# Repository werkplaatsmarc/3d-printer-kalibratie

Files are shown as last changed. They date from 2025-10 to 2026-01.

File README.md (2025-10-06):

# 🛠️ Werkplaats Marc - 3D Printer Kalibratie

**Gratis Nederlandse kalibratie bestanden en tutorials voor perfecte 3D prints**






## 🎯 Complete kalibratie serie

Deze repository bevat **5 van de 10 essentiële kalibratie tests** voor je 3D printer. Alle tests (inclusief Bed Nivellering, Z-Afstand, E-Steps, PID Tuning en Flow Rate) zijn te vinden op **<a href="https://werkplaatsmarc.be" target="_blank">werkplaatsmarc.be</a>** met complete Nederlandse tutorials.

## 📦 Wat zit er in deze repository?

Deze repository bevat **kant-en-klare kalibratie bestanden** voor je 3D printer, allemaal met **Nederlandse instructies**. Geen gedoe met zelf towers maken - download, print, kalibreer.

### 🌡️ Temperatuur Towers

- **PLA** (180-220°C) - Vind de perfecte print temperatuur
- **PETG** (220-250°C) - Test layer adhesie en transparantie
- **ABS** (210-250°C) - Optimaal voor gesloten printers
- **TPU** (210-230°C) - Speciaal voor flexibel filament

### 🔄 Retraction Towers

- **Direct Drive** (1-6mm) - Korte filament pad optimalisatie
- **Bowden** (4-9mm) - Lange tube compensatie
- **TPU Flexibel** (7-12mm) - Voorkomt jamming bij flexibel materiaal

### 🌉 Bridging Test

- **Universeel bridging test** - Optimaliseer cooling en speed voor perfecte overspanningen

### 🎯 Linear Advance Test

- **Universeel pattern** - Werkt voor Marlin K-Factor én Klipper Pressure Advance
- Elimineer blobs en krijg CNC-scherpe hoeken

### 🔧 Input Shaping (GEAVANCEERD)

- **Python scripts** voor automatische resonantie analyse met ADXL345 accelerometer
- **Data verzameling en analyse** - Identificeer resonantie frequenties automatisch
- **Marlin & Klipper** firmware configuratie gegenereerd
- Elimineer ghosting en ringing met 50-80% reductie
- 20-40% hogere betrouwbare print snelheden
- **Volledige Nederlandse tutorial** beschikbaar in `input-shaping/README_NL.md`

### 📚 Nederlandse Instructies

Elke test komt met een **complete setup gids** in het Nederlands:

- Hoe te printen
- Hoe te evalueren
- Hoe waarden toe te passen in je firmware
- Troubleshooting tips

## 🔟 Volledige kalibratie roadmap

Voor de **complete 10-stappen kalibratie** (van bed nivellering tot input shaping), bezoek:
👉 **<a href="https://werkplaatsmarc.be" target="_blank">werkplaatsmarc.be</a>**

Daar vind je:

1. Bed Nivellering
2. Z-Afstand
3. E-Steps
4. Temperatuur ⬅️ _in deze repo_
5. PID Tuning
6. Retraction ⬅️ _in deze repo_
7. Linear Advance ⬅️ _in deze repo_
8. Flow Rate
9. Bridging ⬅️ _in deze repo_
10. Input Shaping ⬅️ _in deze repo_

## 🚀 Hoe te gebruiken?

### Optie 1: Download via website (makkelijkst)

Bezoek **<a href="https://werkplaatsmarc.be" target="_blank">werkplaatsmarc.be</a>** en download de bestanden die je nodig hebt. Elke downloadknop geeft je automatisch het STL/3MF bestand + Nederlandse setup gids.

### Optie 2: Clone deze repository

```bash
git clone https://github.com/werkplaatsmarc/3d-printer-kalibratie.git
cd 3d-printer-kalibratie
```

### Optie 3: Input Shaping Setup

Voor geavanceerde Input Shaping kalibratie:

```bash
cd input-shaping
pip install -r requirements.txt
python adxl_collect.py
python analyze_data.py
```

Zie `input-shaping/README_NL.md` voor de complete tutorial.

## 📁 Repository structuur

```
3d-printer-kalibratie/
├── retraction-towers/
│   ├── retractie-toren-direct-drive-afstand-1-6.3mf
│   ├── retractie-toren-bowden-afstand-4-9.3mf
│   └── retractie-toren-tpu-flexibel-afstand-7-12.3mf
│
├── temperatuur-towers/
│   ├── temperatuur-toren-PLA-180-220.stl
│   ├── temperatuur-toren-PETG-220-250.stl
│   ├── temperatuur-toren-ABS-210-250.stl
│   └── temperatuur-toren-TPU-210-230.stl
│
├── bridging-tests/
│   └── bridging-test-universeel.stl
│
├── linear-advance-tests/
│   └── linear-advance-test-pattern.stl
│
├── input-shaping/
│   ├── adxl_collect.py          # Data verzameling script
│   ├── analyze_data.py           # Automatische analyse
│   ├── requirements.txt          # Python dependencies
│   ├── README_NL.md              # Volledige Nederlandse tutorial
│   └── ringing_tower.stl         # Test print voor validatie
│
└── instructies/
    ├── retraction-setup-gids.txt
    ├── temperatuur-tower-setup.txt
    ├── bridging-setup-gids.txt
    └── linear-advance-setup.txt
```

## 🎥 Video tutorials

Alle kalibratie stappen worden uitgelegd in de **Werkplaats Marc YouTube serie**:

- <a href="https://youtube.com/@werkplaatsmarc" target="_blank">Basis Kalibratie Deel 1</a> - Komt binnenkort
- <a href="https://youtube.com/@werkplaatsmarc" target="_blank">Geavanceerde Kalibratie Deel 2</a> - Komt binnenkort
- <a href="https://youtube.com/@werkplaatsmarc" target="_blank">Input Shaping Tutorial</a> - Komt binnenkort

## 🤝 Bijdragen

Verbeteringen zijn welkom! Open een issue of pull request als je:

- Betere test models hebt
- Fouten vindt in de instructies
- Nieuwe kalibratie tests wilt toevoegen

## 📝 Licentie

MIT License - Gebruik vrijelijk, ook commercieel. Attributie gewaardeerd maar niet verplicht.

## 🔗 Links

- **Website:** <a href="https://werkplaatsmarc.be" target="_blank">werkplaatsmarc.be</a>
- **YouTube:** <a href="https://youtube.com/@werkplaatsmarc" target="_blank">@werkplaatsmarc</a>
- **Discord:** <a href="https://discord.gg/UfztVFcR7g" target="_blank">Community chat</a>

## ❓ Veelgestelde vragen

**Q: Werken deze bestanden met mijn slicer?**  
A: Ja! STL bestanden werken met Cura, PrusaSlicer, Simplify3D, en alle andere slicers. 3MF bestanden hebben extra metadata maar werken ook overal.

**Q: Moet ik iets aanpassen in mijn slicer?**  
A: Voor temperatuur towers: ja, volg de meegeleverde instructies om temperatuur te wijzigen per laag. Voor bridging en linear advance: nee, gewoon printen.

**Q: Wat is Input Shaping en heb ik dat nodig?**  
A: Input Shaping is een geavanceerde techniek om ghosting en ringing te elimineren. Het is optioneel maar geeft drastische kwaliteitsverbetering. Vereist een ADXL345 accelerometer sensor en Python kennis.

**Q: Ik heb een probleem met een test, waar kan ik hulp krijgen?**  
A: Join de <a href="https://discord.gg/UfztVFcR7g" target="_blank">Discord community</a> of stel een vraag onder de YouTube video's. De community helpt graag!

**Q: Waar zijn de andere 5 kalibratie tests?**  
A: Bezoek <a href="https://werkplaatsmarc.be" target="_blank">werkplaatsmarc.be</a> voor de complete 10-stappen kalibratie roadmap met alle tutorials en downloads.

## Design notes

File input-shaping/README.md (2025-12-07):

# 🔧 Input Shaping Kalibratie - Werkplaats Marc

**Nederlandse Input Shaping Tutorial voor 3D Printers**

Elimineer ghosting en ringing op je 3D printer met automatische resonantie analyse. Deze repository bevat tools en documentatie voor zowel **Marlin** als **Klipper** firmware.





---

## 🎯 Welke Firmware Heb Je?

Input Shaping werkt anders op Marlin en Klipper. Kies hieronder:

| **Firmware** | **Gebruik Deze Tools** | **Workflow** |
| --- | --- | --- |
| 🔴 **Marlin**  | ✅ Tools in deze repo  | ADXL345 → USB → PC → Automatische analyse → G-code |
| 🟢 **Klipper** | ❌ Geen tools nodig | ADXL345 → Raspberry Pi → Native Klipper commands |

### Hoe weet ik welke firmware ik heb?

**Methode 1: M115 Command**

```gcode
M115
```

Response toont firmware type en versie.

**Methode 2: Interface**

- **Marlin:** LCD scherm, SD kaart, soms OctoPrint
- **Klipper:** Altijd Raspberry Pi + Mainsail/Fluidd web interface

**Methode 3: Raspberry Pi**

- **Heeft Raspberry Pi:** Waarschijnlijk Klipper
- **Geen Raspberry Pi:** Waarschijnlijk Marlin

---

## 📦 Repository Structuur

```
input-shaping/
├── README.md                          ← Je bent hier
├── ringing_tower.stl                  ← Test print model (beide firmware)
│
├── Marlin/                            ← Voor Marlin gebruikers
│   ├── README-MARLIN.md              ← Volledige Marlin guide
│   ├── Windows/
│   │   ├── adxl_verzameling.bat      ← Windows GUI tool
│   │   ├── INSTALL.bat               ← Windows installer
│   │   └── python/adxl_collect.py    ← Data verzamel + analyse script
│   └── Mac-Linux/
│       ├── adxl_verzameling.sh       ← Mac/Linux tool
│       ├── install.sh                ← Mac/Linux installer
│       └── python/adxl_collect.py    ← Data verzamel + analyse script
│
└── Klipper/                           ← Voor Klipper gebruikers
    └── README-KLIPPER.md             ← Link naar native Klipper tools
```

---

## 🚀 Quick Start

### Voor **Marlin** Gebruikers:

1. **Download de juiste tool:**

   - **Windows:** Download `Marlin/Windows/` map
   - **Mac/Linux:** Download `Marlin/Mac-Linux/` map

2. **Installeer (eerste keer):**

   - **Windows:** Dubbelklik `INSTALL.bat`
   - **Mac/Linux:** Run `./install.sh`

3. **Gebruik de tool:**

   - **Windows:** Dubbelklik `adxl_verzameling.bat`
   - **Mac/Linux:** Run `./adxl_verzameling.sh`

4. **Kies optie [1]** - Volledige kalibratie
5. **Wacht ~30 seconden** voor data verzameling

6. **Krijg direct resultaten!** ⚡

   ```
   📈 X-as resonantie: 35.2 Hz
   📈 Y-as resonantie: 29.8 Hz

   ⚙️ MARLIN G-CODE:
   M593 X F35.2 D0.1
   M593 Y F29.8 D0.1
   M500
   ```

7. **Kopieer G-code** naar je printer terminal

8. **Klaar!** Print en geniet van 50-80% minder ringing! 🎉

### Voor **Klipper** Gebruikers:

👉 Lees `Klipper/README-KLIPPER.md` voor native Klipper workflow.

**TL;DR:** Sluit ADXL345 aan op je Raspberry Pi en gebruik Klipper's eigen tools - deze repository tools zijn NIET nodig voor Klipper!

---

## 📊 Wat Doet Input Shaping?

**Voor Input Shaping:**

- 😞 Zichtbare ringing (golfpatronen) rondom hoeken
- 😞 Ghosting bij snelle bewegingen
- 😞 Beperkte print snelheden
- 😞 Kwaliteit vs snelheid trade-off

**Na Input Shaping:**

- 😊 50-80% reductie in ringing
- 😊 Gladde oppervlakken bij hoge snelheid
- 😊 20-40% hogere betrouwbare snelheden
- 😊 Professionele print kwaliteit

---

## 🔧 Benodigde Hardware

### Voor Marlin:

- BigTreeTech ADXL345 v2.0 (of compatibel)
- USB-C kabel
- Computer (Windows, Mac of Linux)
- 3D printer met Marlin 2.1.x+ firmware

### Voor Klipper:

- ADXL345 accelerometer
- Raspberry Pi met Klipper
- Jumper wires (voor GPIO verbinding)

---

## 📚 Volledige Documentatie

- **Marlin gebruikers:** Lees `Marlin/README-MARLIN.md`
- **Klipper gebruikers:** Lees `Klipper/README-KLIPPER.md`
- **Website:** [werkplaatsmarc.be/input-shaping.html](https://werkplaatsmarc.be/input-shaping.html)
- **YouTube:** [@werkplaatsmarc](https://youtube.com/@werkplaatsmarc)

---

## ❓ Veelgestelde Vragen

### Kan ik Input Shaping gebruiken met mijn printer?

**Marlin:**

- ✅ Marlin 2.1.x of nieuwer
- ✅ `INPUT_SHAPING_X` en `INPUT_SHAPING_Y` enabled in firmware
- ✅ Check met `M593` command (geen error = ondersteund)

**Klipper:**

- ✅ Alle Klipper versies ondersteunen Input Shaping
- ✅ Gewoon `[input_shaper]` toevoegen aan printer.cfg

### Hoe vaak moet ik kalibreren?

Herkalibreer wanneer je:

- 🔧 Mechanische wijzigingen maakt (nieuwe riemen, lagers, etc.)
- 🏗️ Printer verplaatst of herboouwt
- 📦 Grote hardware upgrades doet
- 📉 Verslechtering in print kwaliteit ziet

**Niet nodig bij:**

- ✅ Verschillende filament types
- ✅ Verschillende print snelheden
- ✅ Normale gebruik

### Werkt dit met alle slicers?

Ja! Input Shaping werkt op firmware niveau, dus het werkt met:

- ✅ Cura
- ✅ PrusaSlicer
- ✅ SuperSlicer
- ✅ Simplify3D
- ✅ Alle andere slicers

---

## 🆘 Hulp Nodig?

1. **Lees de README** voor jouw firmware (Marlin of Klipper)
2. **Check de troubleshooting** sectie in de README
3. **Bekijk de YouTube tutorials**
4. **Stel vragen** via GitHub Issues
5. **Join de Discord** community

---

## 🌐 Links & Resources

- **Website:** [werkplaatsmarc.be](https://werkplaatsmarc.be)
- **YouTube:** [@werkplaatsmarc](https://youtube.com/@werkplaatsmarc)
- **Discord:** [discord.gg/UfztVFcR7g](https://discord.gg/UfztVFcR7g)
- **GitHub:** [github.com/werkplaatsmarc](https://github.com/werkplaatsmarc)

---

## 📜 Changelog

### v2.0.0 (December 2025)

- 🎉 **GROTE UPDATE:** Geïntegreerde FFT analyse
- ✨ Direct G-code output na verzameling
- ✨ Geen web upload meer nodig
- ✨ Offline workflow
- ✨ Verbeterde gebruikerservaring
- 🐛 Diverse bug fixes

### v1.0.0 (Oktober 2025)

- 🎉 Eerste release
- ✅ Windows en Mac/Linux tools
- ✅ Online web analyzer
- ✅ Nederlandse documentatie

---

## 📄 Licentie

MIT License - Zie LICENSE bestand voor details.

Open source project voor de Nederlandse maker community! 🇳🇱

---

## 💖 Credits

**Ontwikkeld door:** Marc - Werkplaats Marc  
**Community:** Nederlandse 3D printing makers  
**Dank aan:** Alle testers en contributors!

---

**Veel succes met je Input Shaping kalibratie!** 🚀

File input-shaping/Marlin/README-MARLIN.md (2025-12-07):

# 🔴 Input Shaping voor Marlin - Werkplaats Marc

**Volledige Nederlandse Guide voor Marlin Input Shaping met ADXL345**

Deze guide toont je hoe je Input Shaping configureert op Marlin firmware met de BigTreeTech ADXL345 v2.0 accelerometer.

---

## 📦 Wat Heb Je Nodig?

### Hardware:

- ✅ **BigTreeTech ADXL345 v2.0** accelerometer (of compatibel)
- ✅ **USB-C kabel** (voor verbinding met PC)
- ✅ **Computer** (Windows, Mac of Linux)
- ✅ **3D printer met Marlin 2.1.x+** firmware

### Software:

- ✅ **Python 3.8+** (wordt automatisch geïnstalleerd)
- ✅ **NumPy & SciPy** (voor FFT analyse - automatisch)
- ✅ **PySerial** (voor ADXL345 communicatie - automatisch)

### Firmware Vereisten:

- ✅ Marlin 2.1.x of nieuwer
- ✅ `INPUT_SHAPING_X` enabled in firmware
- ✅ `INPUT_SHAPING_Y` enabled in firmware

**Check of je printer dit ondersteunt:**

```gcode
M593
```

Als je **GEEN** error krijgt → Input Shaping is beschikbaar! ✅

---

## 🚀 Quick Start (5 minuten)

### Stap 1: Download de Tool

**Windows:**

```
Download: Marlin/Windows/
Bestanden:
  - adxl_verzameling.bat
  - INSTALL.bat
  - python/adxl_collect.py
```

**Mac/Linux:**

```
Download: Marlin/Mac-Linux/
Bestanden:
  - adxl_verzameling.sh
  - install.sh
  - python/adxl_collect.py
```

### Stap 2: Installeer (Eerste Keer)

**Windows:**

```
1. Dubbelklik INSTALL.bat
2. Wacht tot installatie voltooid is
3. Klaar!
```

**Mac/Linux:**

```bash
chmod +x install.sh
./install.sh
```

**Wat wordt er geïnstalleerd?**

- Python 3 (als nog niet aanwezig)
- PySerial (voor ADXL345 communicatie)
- NumPy (voor numerieke berekeningen)
- SciPy (voor FFT analyse)

### Stap 3: Hardware Setup

1. **Monteer ADXL345** stevig op de nozzle/printhead

   - Gebruik zip ties, schroeven of dubbelzijdig tape
   - Zorg dat het NIET los zit!

2. **Sluit USB-C kabel aan:**

   - ADXL345 → USB poort op je computer
   - NIET op de printer aansluiten!

3. **Check COM poort** (Windows):

   - Open Apparaatbeheer
   - Zoek "Poorten (COM & LPT)"
   - Noteer COM nummer (bijv. COM3)

4. **Check USB device** (Mac/Linux):

   ```bash
   # Mac
   ls /dev/tty.usb*

   # Linux
   ls /dev/ttyUSB*
   ```

### Stap 4: Volledige Kalibratie

**Windows:**

```
1. Dubbelklik adxl_verzameling.bat
2. Kies [1] Volledige kalibratie
3. Wacht ~30 seconden voor data verzameling
4. Analyse gebeurt automatisch!
5. Kopieer de G-code die op scherm verschijnt
```

**Mac/Linux:**

```bash
./adxl_verzameling.sh
# Kies [1] Volledige kalibratie
# Volg instructies op scherm
```

### Stap 5: Activeer Input Shaping

Kopieer de gegenereerde G-code naar je printer terminal:

```gcode
M593 X F35.2 D0.1
M593 Y F29.8 D0.1
M500
```

**Klaar!** Je printer heeft nu Input Shaping geactiveerd! 🎉

---

## 📋 Gedetailleerde Workflow

### Menu Opties Uitgelegd

De tool heeft 6 menu opties:

```
[1] ⚡ Volledige kalibratie (verzamel + analyse)
[2] 📊 Alleen data verzamelen
[3] 🔬 Analyseer bestaand bestand
[4] ⚙️  Configuratie wijzigen
[5] ❓ Help en instructies
[6] ❌ Afsluiten
```

#### Optie 1: Volledige Kalibratie (AANBEVOLEN)

**Wat gebeurt er:**

1. Tool verzamelt 30 seconden accelerometer data
2. FFT analyse wordt automatisch uitgevoerd
3. Resonantie frequenties worden gedetecteerd
4. G-code wordt gegenereerd en getoond
5. Klaar!

**Wanneer gebruiken:**

- ✅ Eerste keer Input Shaping instellen
- ✅ Na mechanische wijzigingen
- ✅ Als je snel resultaat wilt

**Output voorbeeld:**

```
════════════════════════════════════════════════════════════════════════
📊 RESONANTIE ANALYSE RESULTATEN
════════════════════════════════════════════════════════════════════════

📈 X-AS GEDETECTEERDE RESONANTIES:
   🔴 1. 35.2 Hz (magnitude: 0.0842)
      2. 70.4 Hz (magnitude: 0.0234)
      3. 105.6 Hz (magnitude: 0.0156)

📈 Y-AS GEDETECTEERDE RESONANTIES:
   🔴 1. 29.8 Hz (magnitude: 0.0967)
      2. 59.6 Hz (magnitude: 0.0312)
      3. 89.4 Hz (magnitude: 0.0178)

════════════════════════════════════════════════════════════════════════
⚙️  MARLIN G-CODE CONFIGURATIE
════════════════════════════════════════════════════════════════════════

; X-as Input Shaping
M593 X F35.2 D0.10

; Y-as Input Shaping
M593 Y F29.8 D0.10

; Opslaan in EEPROM (permanent)
M500

; Verificatie (optioneel)
M593
```

#### Optie 2: Alleen Data Verzamelen

**Wanneer gebruiken:**

- Gevorderde gebruikers
- Wilt data bewaren voor later
- Troubleshooting

**Output:**

- CSV bestand in `adxl_data/` directory
- Geen analyse

#### Optie 3: Analyseer Bestaand Bestand

**Wanneer gebruiken:**

- Data al verzameld met optie [2]
- Opnieuw analyseren met andere settings
- Troubleshooting

**Hoe:**

```
1. Kies [3]
2. Zie lijst van beschikbare CSV bestanden
3. Geef bestandsnaam op
4. Analyse wordt uitgevoerd
5. Resultaat op scherm
```

#### Optie 4: Configuratie

**Instelbare parameters:**

- **COM Poort/USB Device:** Waar ADXL345 is aangesloten
- **Duur:** Hoeveel seconden data verzamelen (standaard 30)
- **Sample Rate:** Target (3200 Hz - niet wijzigbaar)

**TIP:** De werkelijke sample rate is ~30-60 Hz door USB beperkingen. Dit is normaal en voldoende voor Input Shaping!

---

## 🔬 Hoe Werkt de Analyse?

### FFT (Fast Fourier Transform)

De tool gebruikt FFT om resonantie frequenties te detecteren:

1. **Data verzameling:** ADXL345 meet trillingen tijdens printer bewegingen
2. **Windowing:** Hanning window voor betere frequentie resolutie
3. **FFT:** Converteer tijdsdomein → frequentie domein
4. **Peak Detection:** Vind dominante resonanties (10-150 Hz range)
5. **G-code Generatie:** Configureer Marlin met gevonden frequenties

### Wat Betekenen de Pieken?

**Primaire piek (🔴):**

- De **grootste** resonantie frequentie
- Dit is de belangrijkste om te compenseren
- Wordt gebruikt in M593 commando

**Harmonischen (secundair):**

- Veelvouden van de primaire frequentie
- Normaal en verwacht
- Worden automatisch gedempt door Input Shaping

**Voorbeeld:**

```
X-as primair: 35 Hz
Harmonischen: 70 Hz (2x), 105 Hz (3x)
```

---

## ⚙️ Marlin Configuratie

### M593 Commando Uitleg

```gcode
M593 X F35.2 D0.1
```

**Parameters:**

- `X` of `Y` → Welke as
- `F35.2` → Frequentie in Hz (van analyse)
- `D0.1` → Damping factor (0.05-0.15)

### Damping Factor Tuning

**Standaard: 0.10** (aanbevolen voor de meeste printers)

**Als je nog steeds ringing ziet:**

- Verhoog naar `D0.12` of `D0.15`
- Test met print

**Als je layer shifts krijgt:**

- Verlaag naar `D0.08` of `D0.05`
- Marlin gebruikt aggressive compensation

**Experimenteer:**

```gcode
; Test verschillende damping waarden
M593 X F35.2 D0.08
M593 Y F29.8 D0.08
M500

; Print test object

; Probeer dan
M593 X F35.2 D0.12
M593 Y F29.8 D0.12
M500
```

### Verificatie

**Check huidige settings:**

```gcode
M593
```

**Output:**

```
echo: Input Shaping:
echo:  M593 X F35.20 D0.10 (ZV)
echo:  M593 Y F29.80 D0.10 (ZV)
```

**Uitschakelen (troubleshooting):**

```gcode
M593 X F0
M593 Y F0
M500
```

---

## 🧪 Testen & Validatie

### Test Print: Ringing Tower

Download `ringing_tower.stl` uit de repository.

**Print settings:**

- Layer height: 0.2mm
- Wall line count: 2
- Infill: 10%
- **Outer wall speed: 100-120 mm/s** ← Belangrijk!
- No supports
- No brim/raft

### Voor/Na Vergelijking

1. **Print ZONDER Input Shaping:**

   ```gcode
   M593 X F0
   M593 Y F0
   M500
   ; Print ringing tower
   ```

2. **Print MET Input Shaping:**

   ```gcode
   M593 X F35.2 D0.1
   M593 Y F29.8 D0.1
   M500
   ; Print ringing tower
   ```

3. **Vergelijk:**
   - Kijk naar hoeken en edges
   - Verwacht 50-80% minder ringing
   - Gebruik goede verlichting

### Verwachte Resultaten

**Voor Input Shaping:**

- 😞 Zichtbare golf-patronen na hoeken
- 😞 "Ghosting" effect
- 😞 Minder scherpe details

**Na Input Shaping:**

- 😊 Gladde oppervlakken
- 😊 Scherpe hoeken
- 😊 Professionele kwaliteit

---

## 🐛 Troubleshooting

### "FOUT: Kan niet verbinden met COM3"

**Oplossingen:**

1. Check of ADXL345 is aangesloten via USB
2. Verifieer COM poort in Apparaatbeheer (Windows)
3. Probeer andere USB poort
4. Installeer CH340 drivers (indien nodig)
5. Check USB kabel (sommige kabels zijn alleen voor laden)

### "Te weinig samples voor analyse"

**Oorzaken:**

- USB communicatie problemen
- ADXL345 niet correct geïnitialiseerd
- Verkeerde COM poort

**Oplossingen:**

1. Herprobeer data verzameling
2. Check USB verbinding
3. Verifieer COM poort configuratie
4. Probeer andere USB poort

### "Geen significante resonanties gevonden"

**Oorzaken:**

- ADXL345 niet stevig gemonteerd
- Data verzameld tijdens stilstand
- Sensor defect

**Oplossingen:**

1. **Controleer montage** - sensor moet met nozzle mee trillen
2. Zorg dat printer kleine bewegingen maakt tijdens verzameling
3. Test ADXL345 op andere printer
4. Verlaag threshold in script (gevorderd)

### "Python niet gevonden"

**Oplossing:**

1. Run `INSTALL.bat` of `install.sh` opnieuw
2. Download Python van python.org
3. **Belangrijk:** Vink "Add Python to PATH" aan tijdens installatie
4. Herstart computer na installatie

### "NumPy/SciPy niet geïnstalleerd"

**Oplossing:**

```bash
# Windows
python -m pip install numpy scipy --break-system-packages

# Mac/Linux
python3 -m pip install numpy scipy
```

### Layer Shifts na Input Shaping

**Dit is een bekend probleem met aggressieve damping!**

**Oplossingen:**

1. Verlaag damping factor:

   ```gcode
   M593 X F35.2 D0.05
   M593 Y F29.8 D0.05
   M500
   ```

2. Disable Input Shaping op één as:

   ```gcode
   M593 X F35.2 D0.08
   M593 Y F0  ; Y-as uit
   M500
   ```

3. Check riemspanning - te los kan layer shifts veroorzaken

---

## 💡 Tips & Tricks

### Optimale Montage van ADXL345

**DO:**

- ✅ Monteer direct op printhead/nozzle
- ✅ Gebruik stevige bevestiging (schroeven > zip ties > tape)
- ✅ Korte, stijve USB kabel
- ✅ Sensor plat tegen oppervlak

**DON'T:**

- ❌ Los of wiebelend gemonteerd
- ❌ Te ver van nozzle (via long chain)
- ❌ Sensor onder hoek
- ❌ Lange, flexibele USB kabel

### Beste Praktijken

1. **Warm de printer op** voordat je data verzamelt

   - Thermal expansion kan resonanties beïnvloeden
   - Verzamel data bij normale print temperatuur

2. **Herhaal meting** bij twijfel

   - Neem 2-3 metingen
   - Gemiddelde zou consistent moeten zijn (±2 Hz)

3. **Test incrementeel**

   - Start met standaard damping (0.10)
   - Tune alleen als nodig

4. **Documenteer je settings**
   - Bewaar G-code outputs
   - Noteer datum en printer configuratie

### Sample Rate Optimalisatie

De tool probeert 3200 Hz maar haalt ~30-60 Hz door USB limitaties.

**Dit is voldoende omdat:**

- Input Shaping frequenties zijn 10-150 Hz
- Nyquist theorem: sample rate > 2× hoogste frequentie
- 60 Hz sample rate detecteert tot 30 Hz perfect
- Harmonischen geven extra data punten

**Wil je hogere sample rate?**

- Gebruik Klipper met SPI verbinding (kan 3200 Hz halen)
- Voor Marlin is USB de enige optie

---

## 📚 Veelgestelde Vragen

### Moet ik dit herhalen na filament wissel?

**Nee!** Input Shaping compenseert mechanische resonanties, niet filament eigenschappen. Één keer kalibreren is genoeg.

### Werkt dit met bowden EN direct drive?

**Ja!** Input Shaping werkt met beide extruder types. De resonanties zijn mechanisch (frame, riemen, lagers), niet filament path gerelateerd.

### Kan ik sneller printen na Input Shaping?

**Ja!** Typisch kan je:

- 20-40% hogere snelheden gebruiken
- Zonder kwaliteitsverlies
- Vooral outer walls kunnen sneller

**Voorbeeld:**

- Outer walls: 60 mm/s → 80-100 mm/s
- Inner walls: 80 mm/s → 120 mm/s

### Moet ik per printer kalibreren?

**Ja, elke printer is uniek!** Zelfs twee identieke printers hebben verschillende resonanties door:

- Assemblage toleranties
- Riemspanning variaties
- Frame stijfheid verschillen
- Leeftijd en slijtage

### Wat als ik Marlin firmware update?

**Instellingen blijven behouden** als je:

- M500 hebt uitgevoerd (EEPROM save)
- EEPROM niet wist tijdens flash

**Als settings verdwenen zijn:**

- Voer G-code opnieuw in (je hebt het opgeslagen, toch? 😉)
- Of herhaal volledige kalibratie

---

## 🔗 Handige Links

- **Web Analyzer (optioneel):** [werkplaatsmarc.be/adxl345-analyzer.html](https://werkplaatsmarc.be/adxl345-analyzer.html)
- **Input Shaping Guide:** [werkplaatsmarc.be/input-shaping.html](https://werkplaatsmarc.be/input-shaping.html)
- **YouTube Tutorial:** [@werkplaatsmarc](https://youtube.com/@werkplaatsmarc)
- **Marlin Docs:** [marlinfw.org](https://marlinfw.org)

---

## 🆘 Support

**Hulp nodig?**

1. Check deze README
2. Bekijk YouTube tutorials
3. Open GitHub Issue
4. Join Discord community

**Discord:** [discord.gg/UfztVFcR7g](https://discord.gg/UfztVFcR7g)

---

**Veel succes met je Marlin Input Shaping kalibratie!** 🚀

_Gemaakt met ❤️ door Marc - Werkplaats Marc_

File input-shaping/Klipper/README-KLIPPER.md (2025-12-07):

# 🟢 Input Shaping voor Klipper - Werkplaats Marc

**Klipper Native Input Shaping Guide**

⚠️ **BELANGRIJK:** Als je Klipper firmware gebruikt, heb je de tools in deze repository **NIET** nodig!

Klipper heeft **native Input Shaping support** die superieur is aan externe tools. Gebruik Klipper's eigen workflow voor de beste resultaten.

---

## 🤔 Waarom Geen Externe Tools voor Klipper?

### Klipper Native Tools zijn Beter:

| Feature | Klipper Native | Deze Repo Tools |
| --- | --- | --- |
| **Sample Rate**  | 3200+ Hz (SPI) | ~30-60 Hz (USB) |
| **Verbinding** | Direct GPIO/SPI | USB naar PC |
| **Analyse** | Op Raspberry Pi | Op PC |
| **Shaper Types** | 7 types (ZV, MZV, EI, 2HUMP_EI, 3HUMP_EI, ZVD, MZV) | Alleen ZV |
| **Configuratie** | Automatisch | Handmatig |
| **Real-time** | Ja | Nee |

**Conclusie:** Klipper's native tools zijn **sneller, nauwkeuriger en gemakkelijker!**

---

## 🚀 Klipper Input Shaping Workflow

### Hardware Aansluiting

**Optie 1: SPI Verbinding (AANBEVOLEN)**

```
ADXL345 → Raspberry Pi GPIO pins
  VCC  → 3.3V (pin 1)
  GND  → Ground (pin 6)
  SCL  → GPIO 11 / SCLK (pin 23)
  SDA  → GPIO 10 / MOSI (pin 19)
  SDO  → GPIO 9 / MISO (pin 21)
  CS   → GPIO 8 / CE0 (pin 24)
```

**Optie 2: USB Verbinding (Simpeler)**

```
ADXL345 → USB poort Raspberry Pi
```

Beide methodes werken, maar **SPI is sneller** (3200 Hz vs 100 Hz).

---

## ⚙️ Klipper Configuratie

### 1. printer.cfg Aanpassen

**Voor SPI verbinding:**

```ini
[mcu rpi]
serial: /tmp/klipper_host_mcu

[adxl345]
cs_pin: rpi:None
spi_bus: spidev0.0

[resonance_tester]
accel_chip: adxl345
probe_points:
    100, 100, 20  # Pas aan voor jouw printer (X, Y, Z)
```

**Voor USB verbinding:**

```ini
[mcu adxl]
serial: /dev/serial/by-id/usb-DEVICE-ID-HERE

[adxl345]
cs_pin: adxl:PA4

[resonance_tester]
accel_chip: adxl345
probe_points:
    100, 100, 20  # Pas aan voor jouw printer
```

### 2. Klipper Herstarten

Via Mainsail/Fluidd interface:

- Klik "FIRMWARE RESTART"
- Of via console: `FIRMWARE_RESTART`

### 3. Test ADXL345 Verbinding

```gcode
ACCELEROMETER_QUERY
```

**Verwacht output:**

```
adxl345 values (x, y, z): 470.719200, 470.719200, 9728.196800
```

Als je errors krijgt, check je bedrading/configuratie.

---

## 📊 Resonantie Meting

### Automatische Resonantie Test

**Voor beide assen tegelijk:**

```gcode
SHAPER_CALIBRATE
```

Dit doet:

1. Test bewegingen op X-as
2. Test bewegingen op Y-as
3. Analyseert resonanties
4. Berekent optimale shaper types
5. Slaat configuratie op

**Proces duurt:** ~2-5 minuten

**Output voorbeeld:**

```
Calculating the best input shaper parameters for x axis
Fitted shaper 'zv' frequency = 35.2 Hz (vibrations = 8.2%, smoothing ~= 0.102)
Fitted shaper 'mzv' frequency = 34.8 Hz (vibrations = 3.1%, smoothing ~= 0.134)
Fitted shaper 'ei' frequency = 39.8 Hz (vibrations = 1.8%, smoothing ~= 0.158)
Fitted shaper '2hump_ei' frequency = 47.4 Hz (vibrations = 0.3%, smoothing ~= 0.188)
Fitted shaper '3hump_ei' frequency = 56.6 Hz (vibrations = 0.1%, smoothing ~= 0.222)
Recommended shaper is ei @ 39.8 Hz
```

### Handmatige Tests (Per As)

**Test alleen X-as:**

```gcode
TEST_RESONANCES AXIS=X
```

**Test alleen Y-as:**

```gcode
TEST_RESONANCES AXIS=Y
```

---

## 🎯 Configuratie Toepassen

### Automatisch (AANBEVOLEN)

Na `SHAPER_CALIBRATE` voer uit:

```gcode
SAVE_CONFIG
```

Dit update automatisch je `printer.cfg` met optimale settings!

### Handmatig

Als je handmatig wilt configureren, voeg toe aan `printer.cfg`:

```ini
[input_shaper]
shaper_freq_x: 35.2
shaper_type_x: ei
shaper_freq_y: 29.8
shaper_type_y: mzv
```

Dan:

```gcode
FIRMWARE_RESTART
```

---

## 📈 Grafieken Genereren (Optioneel)

Voor visuele analyse (advanced):

### 1. Installeer matplotlib op Raspberry Pi

```bash
~/klippy-env/bin/pip install -v matplotlib
```

### 2. Genereer Grafieken

```bash
~/klipper/scripts/calibrate_shaper.py /tmp/resonances_x_*.csv -o /tmp/shaper_calibrate_x.png
~/klipper/scripts/calibrate_shaper.py /tmp/resonances_y_*.csv -o /tmp/shaper_calibrate_y.png
```

### 3. Download Grafieken

Via SSH of Mainsail/Fluidd file browser.

**Grafieken tonen:**

- Resonantie frequenties
- Shaper vergelijking
- Vibration scores

---

## 🔧 Shaper Types Uitgelegd

Klipper ondersteunt **7 shaper types**:

| Shaper | Smoothing | Vibration Reduction | Use Case |
| --- | --- | --- | --- |
| **ZV** | Laagste | Matig | Simpele frames, snelheid prioriteit |
| **MZV** | Laag | Goed | Balans snelheid/kwaliteit |
| **EI** | Medium | Heel goed | Meeste printers (aanbevolen) |
| **2HUMP_EI** | Hoog | Excellent | Meerdere resonanties |
| **3HUMP_EI** | Hoogste | Best | Complexe resonanties |
| **ZVD** | Laag-medium | Zeer goed | Alternative voor EI |
| **MZV** | Medium | Zeer goed | Gevoelige frames |

**Standaard aanbeveling:** `EI` of `MZV`

Klipper kiest automatisch de beste voor jouw printer!

---

## ✅ Verificatie & Testen

### Test Print: Ringing Tower

Download `ringing_tower.stl` uit deze repository.

**Print settings:**

- Layer height: 0.2mm
- Walls: 2
- Infill: 10%
- **Outer wall speed: 100-150 mm/s** ← Belangrijk!

### Voor/Na Vergelijking

**Zonder Input Shaping:**

```gcode
SET_INPUT_SHAPER SHAPER_FREQ_X=0 SHAPER_FREQ_Y=0
; Print ringing tower
```

**Met Input Shaping:**

```gcode
; Gebruik auto-configured settings (na SAVE_CONFIG)
; Print ringing tower
```

**Vergelijk:**

- Verwacht 70-95% reductie in ringing (beter dan Marlin!)
- Scherpe hoeken zelfs bij hoge snelheid
- Minimale smoothing

---

## 🐛 Troubleshooting

### "adxl345: Invalid adxl345 id"

**Oorzaak:** ADXL345 niet correct aangesloten of defect

**Oplossingen:**

1. Check bedrading (SPI pins)
2. Verifieer 3.3V power (NIET 5V!)
3. Test met `ACCELEROMETER_QUERY`
4. Probeer andere ADXL345 sensor

### "Unable to read adxl345 data"

**Oorzaak:** SPI communicatie probleem

**Oplossingen:**

1. Enable SPI op Raspberry Pi:
   ```bash
   sudo raspi-config
   # Interfacing Options → SPI → Enable
   ```
2. Check kabel lengte (max 30cm voor SPI)
3. Gebruik shielded cable voor langere afstanden

### Grafieken zijn "noisy"

**Oorzaak:** Slechte montage of mechanische problemen

**Oplossingen:**

1. **Controleer montage** - ADXL345 moet STEVIG zitten
2. Gebruik kortere, stijvere kabels
3. Check riemspanning
4. Verify frame stijfheid

### "recommended shaper exceeds maximum smoothing"

**Betekenis:** Printer heeft sterke resonanties

**Oplossingen:**

1. Accepteer de aanbeveling (Klipper weet wat het doet)
2. Of fix mechanische problemen:
   - Riemspanning check
   - Lagers controleren
   - Frame verstevigen
3. Re-calibrate na fixes

---

## 💡 Advanced Tips

### Meerdere ADXL345 Sensors

Voor ultra-precise kalibratie kan je 2 sensors gebruiken:

- Eén op toolhead (X + Y resonanties)
- Eén op bed (Y + bed resonanties)

**Config:**

```ini
[adxl345 hotend]
cs_pin: rpi:None
spi_bus: spidev0.0

[adxl345 bed]
cs_pin: rpi:None
spi_bus: spidev0.1

[resonance_tester]
accel_chip: adxl345 hotend
accel_chip_y: adxl345 bed
probe_points: 100, 100, 20
```

### Real-time Tuning

Klipper kan Input Shaping **tijdens print** aanpassen:

```gcode
SET_INPUT_SHAPER SHAPER_TYPE_X=2HUMP_EI SHAPER_FREQ_X=37.0
; Print test
; Evalueer
SET_INPUT_SHAPER SHAPER_TYPE_X=EI SHAPER_FREQ_X=39.0
; Print test
```

Ideaal voor fine-tuning!

### Per-extruder Calibration (Multi-extruder)

Klipper kan verschillende shapers per extruder:

```ini
[input_shaper]
shaper_freq_x: 35.2
shaper_type_x: ei

# T0 (extruder 0)
[extruder]
# ... config ...

# T1 (extruder 1) - andere shaper
[extruder1]
# ... config ...
```

---

## 🔗 Officiele Klipper Documentatie

**Volledige Klipper Input Shaping Guide:**
https://www.klipper3d.org/Resonance_Compensation.html

**ADXL345 Setup:**
https://www.klipper3d.org/Measuring_Resonances.html

**Klipper Command Reference:**
https://www.klipper3d.org/G-Codes.html#input-shaper

---

## ❓ Veelgestelde Vragen

### Moet ik v2.0 tools gebruiken met Klipper?

**NEE!** Gebruik Klipper's native tools. Deze zijn:

- Sneller (SPI vs USB)
- Nauwkeuriger (3200 Hz vs 60 Hz)
- Automatischer (geen handmatige G-code)
- Beter geïntegreerd

### Kan ik v2.0 tools als backup gebruiken?

Ja, maar het heeft **geen voordelen**. Klipper's tools zijn superieur in elk aspect.

**Enige reden om v2.0 tools te gebruiken:**

- Je wilt data delen met Marlin gebruikers
- Academic interest in FFT analyse
- Debugging doeleinden

### Werkt Klipper Input Shaping met elke printer?

**Ja!** Klipper ondersteunt:

- CoreXY
- Cartesian (Prusa-style)
- Delta
- Polar
- SCARA
- Alle andere kinematica types

### Hoe vaak moet ik re-calibreren?

**Herkalibreer na:**

- Mechanische wijzigingen (riemen, lagers, frame)
- Firmware updates (soms)
- Als print kwaliteit verslechtert

**Niet nodig na:**

- Filament wissel
- Slicer settings wijziging
- Normale gebruik

---

## 📊 Klipper vs Marlin Input Shaping

| Feature | Klipper | Marlin |
| --- | --- | --- |
| **Shaper Types** | 7 types | 1 type (ZV) |
| **Sample Rate** | 3200+ Hz | 30-60 Hz |
| **Configuratie** | Auto | Handmatig |
| **Real-time Tuning**  | Ja | Nee |
| **Grafische Analyse** | Ja | Via web tool |
| **Ease of Use** | ⭐⭐⭐⭐⭐ | ⭐⭐⭐ |
| **Effectiviteit** | 70-95% reductie | 50-80% reductie |

**Winnaar:** 🟢 **Klipper!**

---

## 🌐 Links & Resources

- **Klipper Docs:** [klipper3d.org](https://www.klipper3d.org)
- **Klipper Discord:** [discord.klipper3d.org](https://discord.klipper3d.org)
- **Werkplaats Marc:** [werkplaatsmarc.be](https://werkplaatsmarc.be)
- **YouTube:** [@werkplaatsmarc](https://youtube.com/@werkplaatsmarc)

---

## 🎉 Conclusie

Als Klipper gebruiker:

1. ✅ Gebruik Klipper's native Input Shaping
2. ✅ Volg de officiele Klipper documentatie
3. ✅ Geniet van superieure resultaten!

**Geen externe tools nodig!** Klipper heeft alles ingebouwd. 🚀

---

**Happy Printing!**

_Deze guide is onderdeel van Werkplaats Marc - Nederlandse 3D Printing Community_
---

**Veel succes met je Klipper Input Shaping kalibratie! 🚀**

← [Terug naar hoofdpagina](../README.md) | [Naar Marlin instructies](../Marlin/README-MARLIN.md)

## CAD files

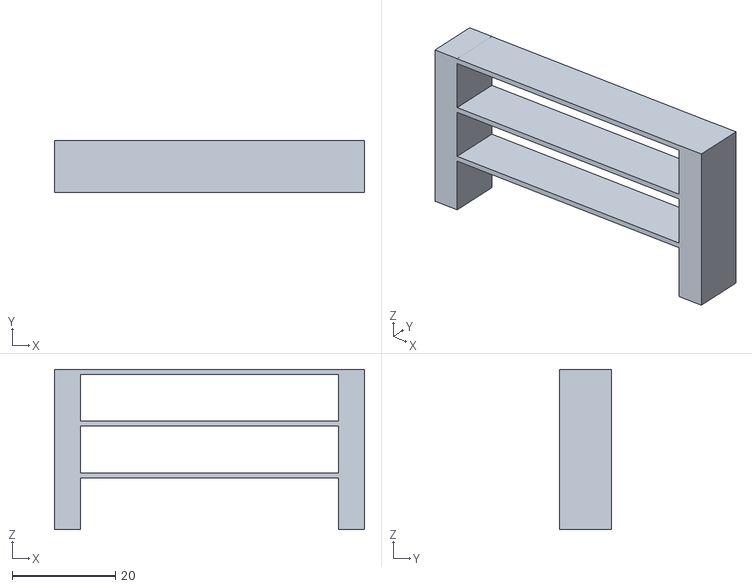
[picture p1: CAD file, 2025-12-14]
bridging-tests/bridging-test-50mm.stl
60.0 x 10.0 x 31.0

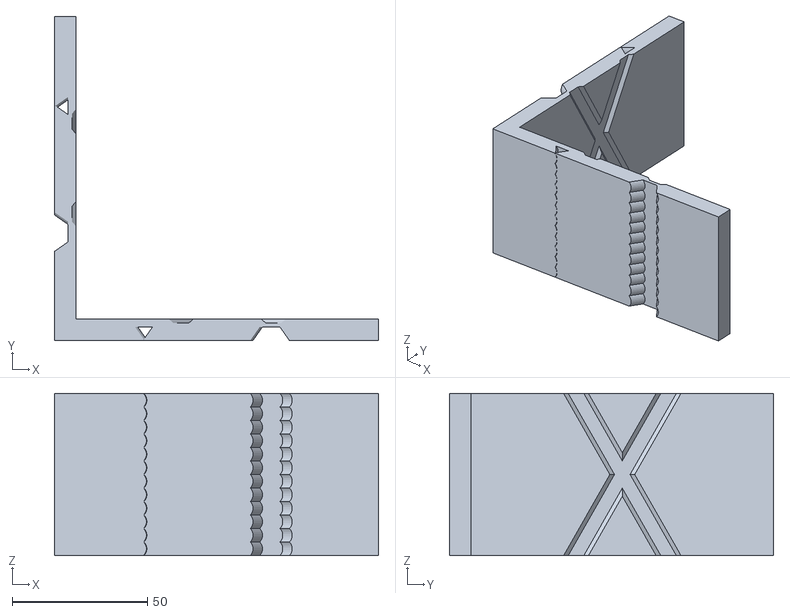
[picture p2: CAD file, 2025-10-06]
input-shaping/ringing_tower.stl
120.0 x 120.0 x 60.0

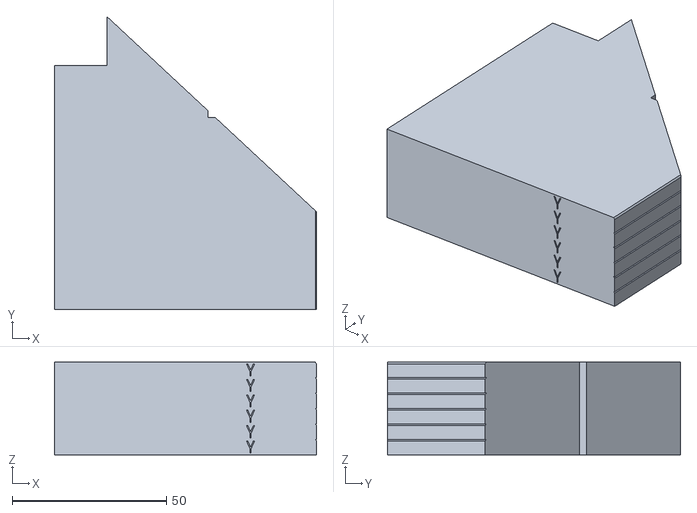
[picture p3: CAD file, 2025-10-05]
linear-advance-tests/linear-advance-test-pattern.stl
85.0 x 95.0 x 30.0

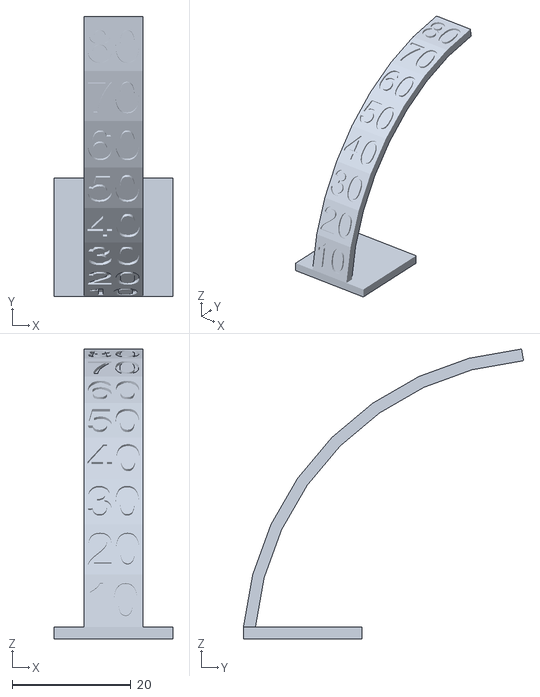
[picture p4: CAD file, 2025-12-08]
overhang-tests/overhang-angle-test.stl
20.0 x 47.3 x 48.9

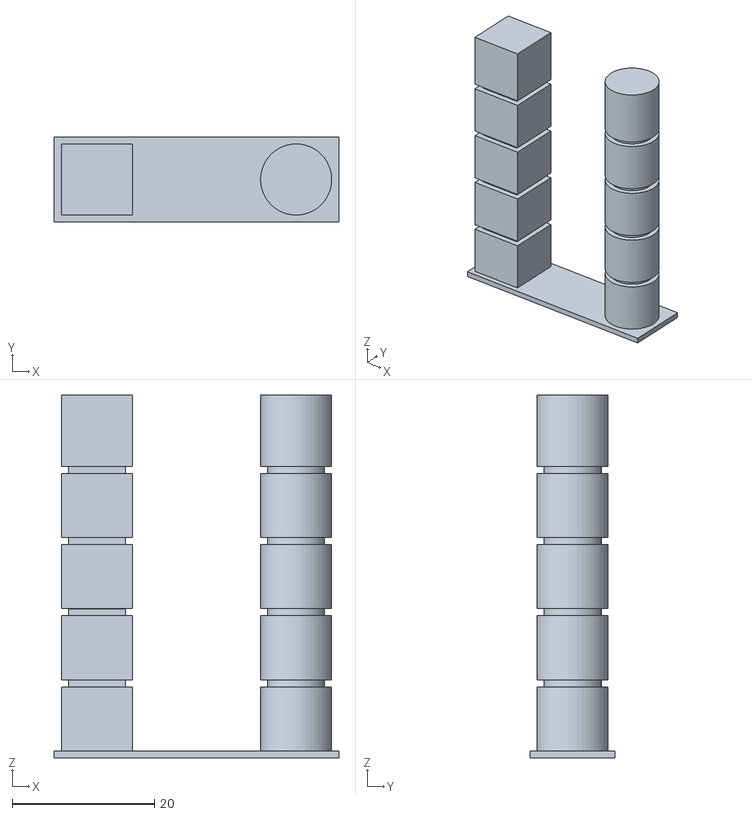
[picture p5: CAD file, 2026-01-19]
retraction-towers/retraction-tower-blank.stl
40.0 x 12.0 x 51.0

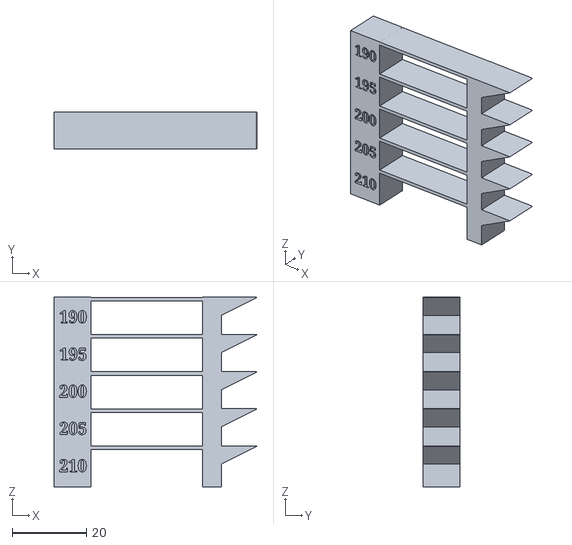
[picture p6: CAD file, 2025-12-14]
temperatuur-towers/temp-tower-PLA.stl
54.6 x 10.0 x 51.0

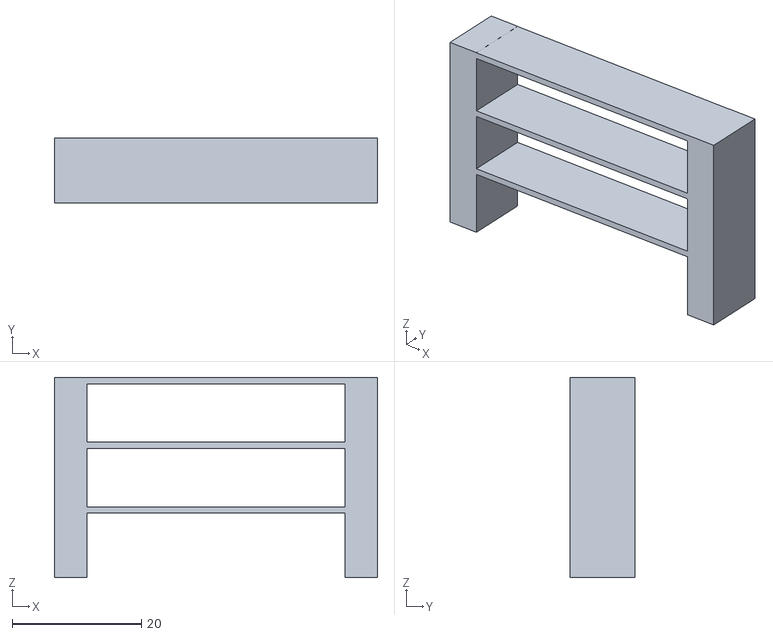
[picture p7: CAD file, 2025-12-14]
bridging-tests/bridging-test-40mm.stl
50.0 x 10.00 x 31.0

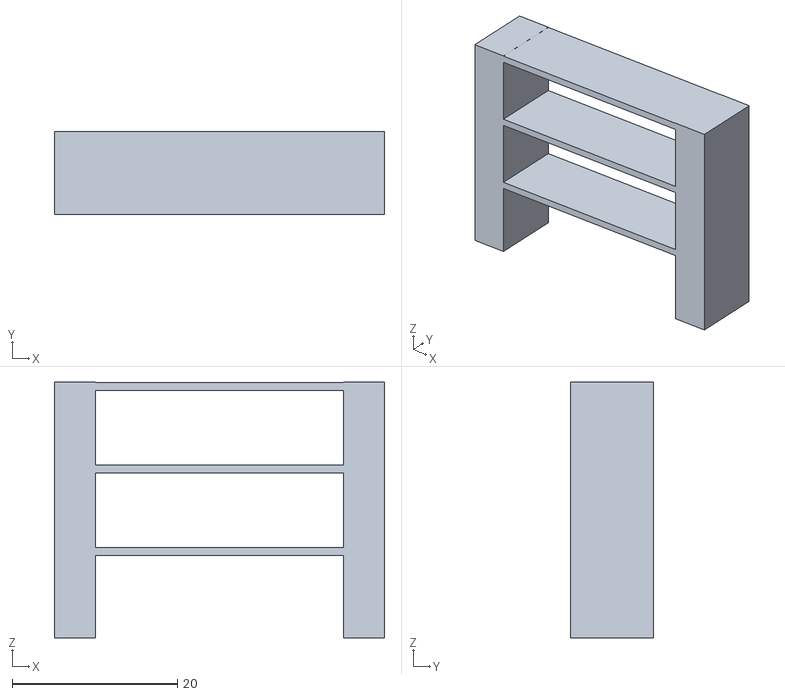
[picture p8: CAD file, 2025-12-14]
bridging-tests/bridging-test-30mm.stl
40.0 x 10.0 x 31.0

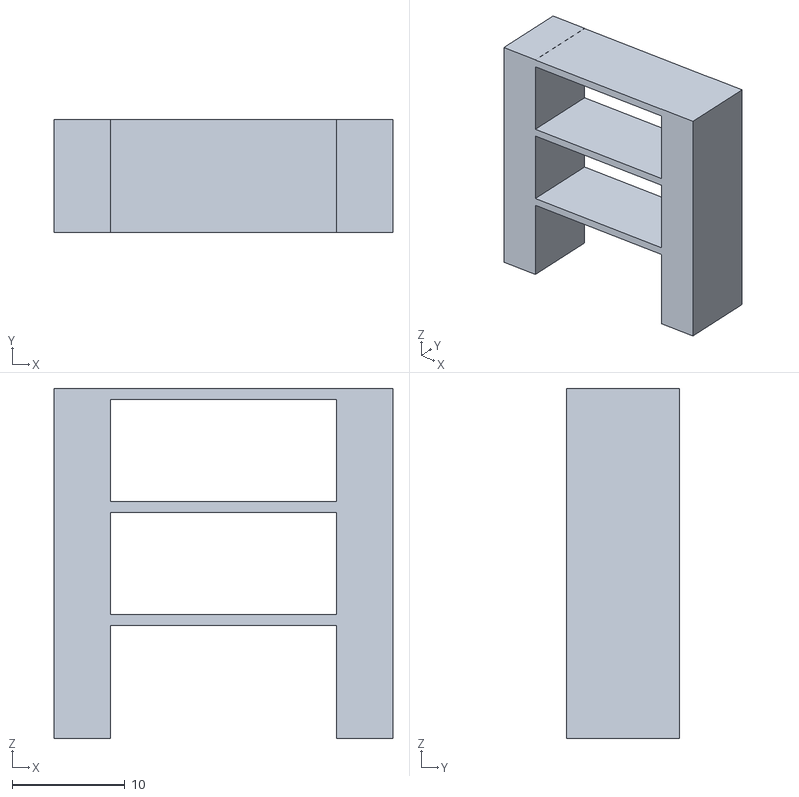
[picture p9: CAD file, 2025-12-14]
bridging-tests/bridging-test-20mm.stl
30.0 x 10.0 x 31.0

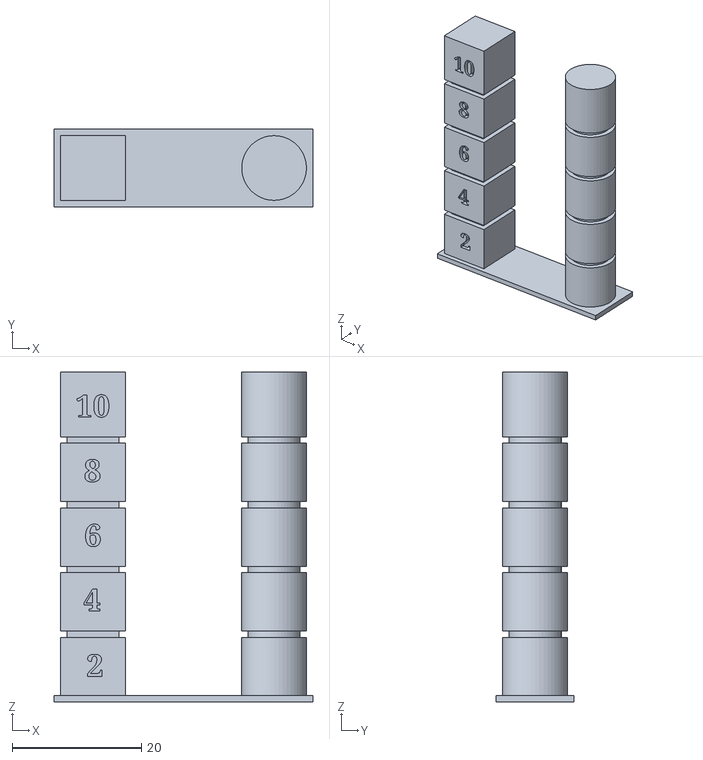
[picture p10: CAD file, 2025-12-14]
retraction-towers/retraction-tower-bowden.stl
40.0 x 12.0 x 51.0

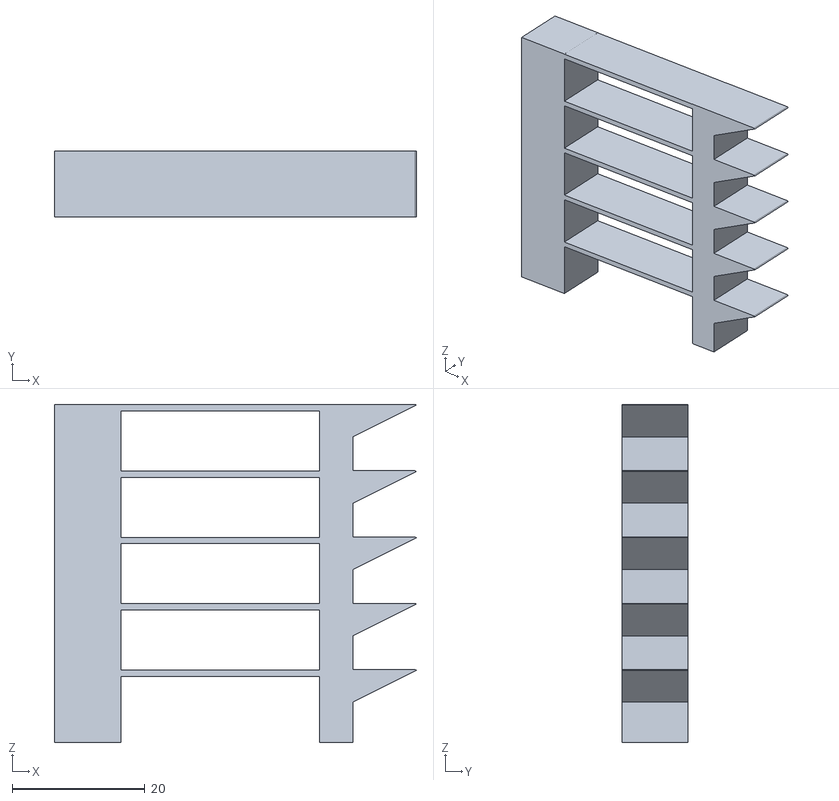
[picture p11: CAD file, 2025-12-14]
temperatuur-towers/temp-tower-universal.stl
54.6 x 10.0 x 51.0

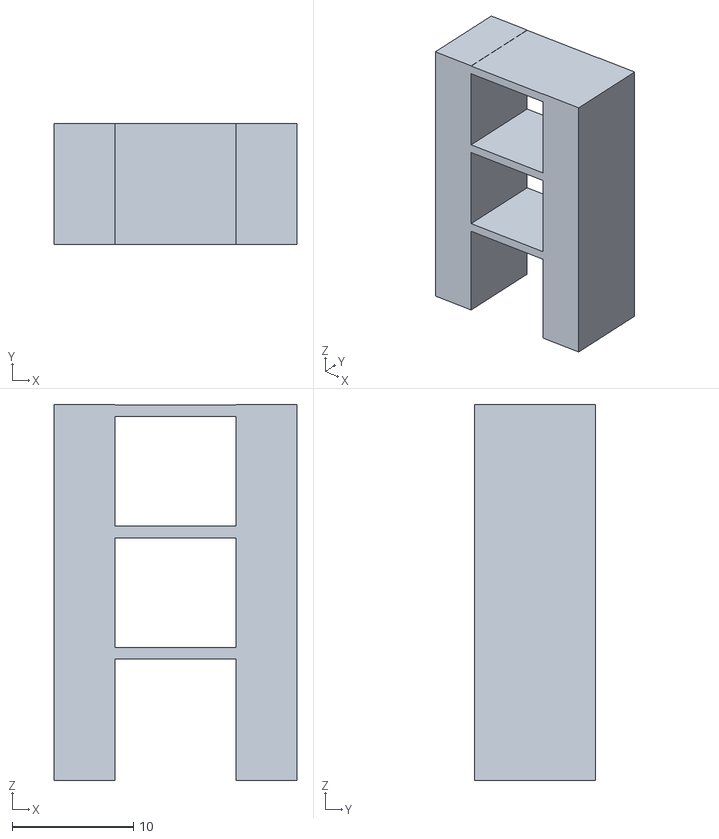
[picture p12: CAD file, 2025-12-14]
bridging-tests/bridging-test-10mm.stl
20.0 x 10.0 x 31.0

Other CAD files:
retraction-towers/retraction-tower-direct.stl
temperatuur-towers/temp-tower-TPU.stl
retraction-towers/retraction-tower-tpu.stl
temperatuur-towers/temp-tower-PETG.stl
temperatuur-towers/temp-tower-ABS.stl

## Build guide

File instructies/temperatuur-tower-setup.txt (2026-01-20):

================================================================================
TEMPERATUUR TOWER KALIBRATIE - CURA HANDLEIDING
Werkplaats Marc - werkplaatsmarc.be
================================================================================

WAT IS EEN TEMPERATUUR TOWER?
------------------------------
Test verschillende temperaturen in één print om de optimale temperatuur te 
vinden voor elk specifiek filament. Elke sectie print op een andere temperatuur.

METHODE 1: CALIBRATION SHAPES PLUGIN (MAKKELIJKST!)
================================================================================

INSTALLATIE
-----------
1. Open Cura
2. Klik: Marketplace (rechtsboven)
3. Zoek: "Calibration Shapes"
4. Klik: Install (van 5@xes)
5. Herstart Cura

TEMPERATUUR TOWER GENEREREN
----------------------------
1. Klik: Extensions > Part for calibration
2. Kies je filament type:
   - Add a PLA Temp Tower
   - Add a PETG Temp Tower
   - Add a ABS Temp Tower
   (of gebruik "Add a Temp Tower" voor custom range)

3. De tower wordt automatisch toegevoegd!

4. Ga naar: Extensions > Post Processing > Modify G-Code
5. Je ziet automatisch "TempFanTower" script toegevoegd
6. Controleer de instellingen (normaal al correct!)

7. Slice en print!

WAAROM DIT DE BESTE METHODE IS:
- Automatisch tower model
- Automatisch post processing script
- Geen handmatig rekenwerk
- Direct klaar voor printen

METHODE 2: POST PROCESSING SCRIPT (HANDMATIGE STL)
================================================================================

DEZE METHODE ALS JE CALIBRATION SHAPES NIET WILT INSTALLEREN

STAP 1: Download Tower STL
---------------------------
Download van werkplaatsmarc.be/temperatuur.html:
- temp-tower-PLA.stl (180-220°C)
- temp-tower-PETG.stl (220-250°C)
- temp-tower-ABS.stl (210-250°C)
- temp-tower-TPU.stl (210-230°C)

STAP 2: Import in Cura
-----------------------
1. Sleep STL naar Cura
2. Slice NIET meteen!

STAP 3: Post Processing Script Toevoegen
-----------------------------------------
1. Ga naar: Extensions > Post Processing > Modify G-Code
2. Klik: Add a script
3. Kies: ChangeAtZ (meerdere keren toevoegen!)

CONFIGURATIE PER FILAMENT TYPE:

═══════════════════════════════════════════════════════════════════════════

PLA (180-220°C)
===============

Laag hoogte: 0.2mm
Elke sectie = 50 layers (10mm @ 0.2mm layer height)

Voeg 8x ChangeAtZ script toe met deze waardes:

Script 1:
- Trigger: Height
- Change Height: 10.0
- Change Extruder 1 Temp: ☑
- Extruder 1 Temp: 215

Script 2:
- Trigger: Height  
- Change Height: 20.0
- Change Extruder 1 Temp: ☑
- Extruder 1 Temp: 210

Script 3:
- Trigger: Height
- Change Height: 30.0
- Change Extruder 1 Temp: ☑
- Extruder 1 Temp: 205

Script 4:
- Trigger: Height
- Change Height: 40.0
- Change Extruder 1 Temp: ☑
- Extruder 1 Temp: 200

Script 5:
- Trigger: Height
- Change Height: 50.0
- Change Extruder 1 Temp: ☑
- Extruder 1 Temp: 195

Script 6:
- Trigger: Height
- Change Height: 60.0
- Change Extruder 1 Temp: ☑
- Extruder 1 Temp: 190

Script 7:
- Trigger: Height
- Change Height: 70.0
- Change Extruder 1 Temp: ☑
- Extruder 1 Temp: 185

Script 8:
- Trigger: Height
- Change Height: 80.0
- Change Extruder 1 Temp: ☑
- Extruder 1 Temp: 180

Start temperatuur in Cura: 220°C
Optimaal resultaat meestal: 200-210°C

═══════════════════════════════════════════════════════════════════════════

PETG (220-250°C)
================

Laag hoogte: 0.2mm
Elke sectie = 40 layers (8mm @ 0.2mm layer height)

Voeg 3x ChangeAtZ script toe:

Script 1:
- Trigger: Height
- Change Height: 8.0
- Change Extruder 1 Temp: ☑
- Extruder 1 Temp: 240

Script 2:
- Trigger: Height
- Change Height: 16.0
- Change Extruder 1 Temp: ☑
- Extruder 1 Temp: 230

Script 3:
- Trigger: Height
- Change Height: 24.0
- Change Extruder 1 Temp: ☑
- Extruder 1 Temp: 220

Start temperatuur in Cura: 250°C
Optimaal resultaat meestal: 235-245°C
⚠️ Part cooling: 30-50%
⚠️ Bed: 70-80°C

═══════════════════════════════════════════════════════════════════════════

ABS (210-250°C)
===============

Laag hoogte: 0.2mm
Elke sectie = 30 layers (6mm @ 0.2mm layer height)

Voeg 4x ChangeAtZ script toe:

Script 1:
- Trigger: Height
- Change Height: 6.0
- Change Extruder 1 Temp: ☑
- Extruder 1 Temp: 240

Script 2:
- Trigger: Height
- Change Height: 12.0
- Change Extruder 1 Temp: ☑
- Extruder 1 Temp: 230

Script 3:
- Trigger: Height
- Change Height: 18.0
- Change Extruder 1 Temp: ☑
- Extruder 1 Temp: 220

Script 4:
- Trigger: Height
- Change Height: 24.0
- Change Extruder 1 Temp: ☑
- Extruder 1 Temp: 210

Start temperatuur in Cura: 250°C
Optimaal resultaat meestal: 240-250°C
⚠️ VEREIST: Gesloten behuizing
⚠️ Bed: 90-110°C
⚠️ Ventilatie (dampen!)

═══════════════════════════════════════════════════════════════════════════

TPU (210-230°C)
===============

Laag hoogte: 0.2mm
Elke sectie = 40 layers (8mm @ 0.2mm layer height)

Voeg 2x ChangeAtZ script toe:

Script 1:
- Trigger: Height
- Change Height: 8.0
- Change Extruder 1 Temp: ☑
- Extruder 1 Temp: 220

Script 2:
- Trigger: Height
- Change Height: 16.0
- Change Extruder 1 Temp: ☑
- Extruder 1 Temp: 210

Start temperatuur in Cura: 230°C
Optimaal resultaat meestal: 215-225°C
⚠️ Print speed: 10-20mm/s (LANGZAAM!)
⚠️ Retraction: Minimaal of 0mm

═══════════════════════════════════════════════════════════════════════════

TOWER EVALUEREN
================================================================================

CHECK PER SECTIE:
-----------------
✓ Overhang kwaliteit (schuine wanden)
✓ Bridging prestatie (hangende delen)
✓ Layer adhesie (laag hechting)
✓ Oppervlakte kwaliteit (gladheid)
✓ Stringing (draadjes tussen delen)

BESTE SECTIE = OPTIMALE TEMPERATUUR!

BELANGRIJKE TIPS
================================================================================

✓ Calibration Shapes plugin is MAKKELIJKSTE methode
✓ Vergeet niet scripts te verwijderen voor volgende print!
✓ Test elke nieuwe filament rol (variatie tussen batches)
✓ Noteer beste temperatuur per merk/type

✗ Vergeet niet om na de test de scripts te verwijderen!
✗ Check altijd de G-code preview voor je print

VRAGEN?
================================================================================
YouTube: @werkplaatsmarc
Website: werkplaatsmarc.be
Discord: discord.gg/UfztVFcR7g

Video: Basis Kalibratie Deel 1
https://youtu.be/bODkCM9mSGk

Succes met calibreren!
- Marc

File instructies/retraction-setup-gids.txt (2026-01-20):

================================================================================
RETRACTION TOWER KALIBRATIE - CURA HANDLEIDING
Werkplaats Marc - werkplaatsmarc.be
================================================================================

RETRACTION TOWER TEST
---------------------
Test automatisch verschillende retraction afstanden in één print.
Tower heeft 2 kolommen met 18mm gap - check tussen kolommen voor stringing!

METHODE 1: CALIBRATION SHAPES PLUGIN (MAKKELIJKST!)
================================================================================

INSTALLATIE
-----------
1. Open Cura
2. Klik: Marketplace (bovenin menu)
3. Zoek: "Calibration Shapes"
4. Klik: Install (van 5@xes)
5. Herstart Cura

RETRACTION TOWER GENEREREN
---------------------------
1. Klik: Extensions > Calibration Shapes > Add a Retraction Tower
2. Plugin genereert automatisch de tower!
3. Slice normaal
4. Print en evalueer

WAAROM DIT DE BESTE METHODE IS:
- Automatisch tower model
- Geen handmatig werk
- Direct klaar voor printen

METHODE 2: POST PROCESSING SCRIPT (INGEBOUWD IN CURA)
================================================================================

DEZE METHODE ALS JE CALIBRATION SHAPES NIET WILT INSTALLEREN

STAP 1: Download Tower STL
---------------------------
Download van werkplaatsmarc.be/retraction.html:
- retraction-tower-direct.stl (Direct Drive)
- retraction-tower-bowden.stl (Bowden)
- retraction-tower-tpu.stl (TPU)

STAP 2: Import en Slice
------------------------
1. Sleep STL naar Cura
2. Zet retraction settings:
   - Enable Retraction: AAN
   - Retraction Distance: Start waarde (bijv. 2mm voor bowden)
   - Retraction Speed: 25mm/s (bowden) of 45mm/s (direct drive)
3. Slice de tower

STAP 3: Post Processing Script Toevoegen
-----------------------------------------
1. Ga naar: Extensions > Post Processing > Modify G-Code
2. Klik: Add a script
3. Kies: RetractTower
4. Stel in:

   VOOR DIRECT DRIVE:
   VOOR DIRECT DRIVE:
   - Command: Distance
   - Starting Value: 0.2
   - Value Increment: 0.2
   - Change Layer: elke 25 layers (voor 0.2mm layer height = 5mm)
   
   VOOR BOWDEN:
   - Command: Distance  
   - Starting Value: 2
   - Value Increment: 2
   - Change Layer: elke 25 layers (voor 0.2mm layer height = 5mm)

5. Klik: Close
6. Slice opnieuw (Cura past nu G-code automatisch aan!)
7. Print!

BELANGRIJKE OPMERKING:
De script werkt ALLEEN als je "Enable Retraction" hebt aangezet in Cura
en een retraction distance > 0mm hebt ingesteld!

TOWER EVALUEREN
================================================================================

LEES VAN ONDER NAAR BOVEN
--------------------------
1. Onderste sectie = Laagste retraction waarde
2. Check tussen de twee kolommen voor stringing draden  
3. Welke sectie heeft MINSTE stringing?
4. Noteer die retraction waarde

BESTE WAARDE TOEPASSEN IN CURA
-------------------------------
1. Zoek "Retraction Distance" in settings
2. Vul de beste waarde in
3. Save als nieuw filament profiel

TROUBLESHOOTING
================================================================================

TE VEEL STRINGING?
------------------
→ Verhoog Retraction Distance met 0.2-0.5mm stappen
→ Verlaag nozzle temperatuur met 5°C
→ Verhoog Travel Speed
→ Check of filament droog is

UNDER-EXTRUSIE NA TRAVEL?
--------------------------
→ Verlaag Retraction Distance met 0.2mm stappen
→ Verhoog Retraction Speed  
→ Check extruder spanning (te strak = slippen)
→ Check bowden tube (slijtage?)

BLOBS BIJ START NIEUWE LAAG?
-----------------------------
→ Retraction Distance iets verhogen
→ "Retraction at Layer Change" activeren
→ Z-Hop activeren (optioneel)

BELANGRIJKE OPMERKINGEN
================================================================================

✓ Calibration Shapes plugin is MAKKELIJKSTE methode
✓ Post Processing Script werkt alleen met "Enable Retraction" AAN
✓ Noteer je beste settings per filament type
✓ Verschillende filament merken = verschillende settings!

✗ NOOIT boven 2mm voor Direct Drive
✗ NOOIT boven 15mm voor Bowden  
✗ TPU heel voorzichtig met retraction (vaak 0mm beste!)

VRAGEN?
================================================================================
YouTube: @werkplaatsmarc
Website: werkplaatsmarc.be
Discord: discord.gg/UfztVFcR7g

Succes met calibreren!
- Marc

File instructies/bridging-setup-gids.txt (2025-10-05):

BRIDGING SETUP - ALLE MATERIALEN
=================================

ALGEMENE INSTELLINGEN
---------------------
• Laag hoogte: 0.2mm
• Bridge flow: 95%
• Geen supports

═══════════════════════════════════════════════════════

PLA
---
STANDARD COOLING (1 fan):
• Part cooling: 100%
• Bridge speed: 15-25mm/s
• Temperatuur: 195-200°C
• Max span: 40-50mm

UPGRADED COOLING (2+ fans):
• Part cooling: 100%
• Bridge speed: 20-30mm/s
• Temperatuur: 195-200°C
• Max span: 50-60mm

PETG
----
STANDARD COOLING:
• Part cooling: 50-70%
• Bridge speed: 20-30mm/s
• Temperatuur: 230-235°C
• Max span: 30-40mm

UPGRADED COOLING:
• Part cooling: 70-90%
• Bridge speed: 25-35mm/s
• Temperatuur: 230-235°C
• Max span: 40-50mm

ABS
---
STANDARD COOLING:
• Part cooling: 30-50%
• Bridge speed: 25-35mm/s
• Temperatuur: 245-250°C
• Max span: 25-35mm
⚠ Gesloten behuizing vereist

UPGRADED COOLING:
• Part cooling: 50-70%
• Bridge speed: 30-40mm/s
• Temperatuur: 245-250°C
• Max span: 35-45mm
⚠ Gesloten behuizing vereist

TPU
---
• Part cooling: 50-80%
• Bridge speed: 10-20mm/s (LANGZAAM!)
• Temperatuur: 215-225°C
• Max span: 20-30mm
• Minimale retraction

═══════════════════════════════════════════════════════

EVALUATIE
---------
✓ Minimale sagging
✓ Rechte lijnen (geen buiging)
✓ Goede adhesie aan pillars
✓ Geen stringing

TIPS
----
• Lagere temp = betere bridging
• Hogere fan = betere bridging
• Langzamer = betere bridging
• Eerste layer bridge is kritisch

═══════════════════════════════════════════════════════
YouTube: Werkplaats Marc - Geavanceerde Kalibratie

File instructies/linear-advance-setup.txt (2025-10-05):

LINEAR ADVANCE SETUP - MARLIN & KLIPPER
========================================

BESTAND
-------
linear-advance-test-pattern.stl

ALGEMENE INSTELLINGEN
---------------------
• Laag hoogte: 0.2mm
• Print speed: 60-120mm/s
• Infill: 15%
• Print tijd: 20-30 min

═══════════════════════════════════════════════════════

HOE TE GEBRUIKEN
================

1. Download linear-advance-test-pattern.stl
2. Import in je slicer
3. Voeg G-code toe voor jouw firmware (zie hieronder)
4. Print en evalueer

═══════════════════════════════════════════════════════

MARLIN K-FACTOR
===============

WAARDES DIRECT DRIVE
--------------------
Range: 0.0 - 0.3
Stappen: 0.03
Typisch eindresultaat: 0.1-0.15

PLA:  0.05-0.15
PETG: 0.08-0.20
ABS:  0.06-0.15

WAARDES BOWDEN
--------------
Range: 0.0 - 0.8
Stappen: 0.05
Typisch eindresultaat: 0.4-0.6

PLA:  0.3-0.6
PETG: 0.4-0.8
ABS:  0.3-0.7

CURA - SEARCH AND REPLACE
--------------------------
Extensions > Post Processing > Modify G-Code
Add script "Search and Replace" (meerdere keren!)

Voorbeeld Direct Drive:
Search: ;LAYER:10  | Replace: ;LAYER:10\nM900 K0.00
Search: ;LAYER:20  | Replace: ;LAYER:20\nM900 K0.03
Search: ;LAYER:30  | Replace: ;LAYER:30\nM900 K0.06
... etc tot K0.30

Voorbeeld Bowden:
Search: ;LAYER:10  | Replace: ;LAYER:10\nM900 K0.00
Search: ;LAYER:20  | Replace: ;LAYER:20\nM900 K0.05
Search: ;LAYER:30  | Replace: ;LAYER:30\nM900 K0.10
... etc tot K0.80

INSTELLEN NA TEST
-----------------
M900 K0.15    ; Stel K-factor in
M500          ; Bewaar naar EEPROM

OF in Cura start G-code:
M900 K0.15

═══════════════════════════════════════════════════════

KLIPPER PRESSURE ADVANCE
=========================

WAARDES DIRECT DRIVE
--------------------
Range: 0.000 - 0.060
Stappen: 0.005
Typisch eindresultaat: 0.025-0.04

WAARDES BOWDEN
--------------
Range: 0.000 - 0.120
Stappen: 0.005
Typisch eindresultaat: 0.06-0.09

ORCASLICER/PRUSASLICER
----------------------
Gebruik "Custom G-code" per layer:
1. Preview > Layer slider
2. Rechtermuisklik op layer > Insert custom G-code
3. Voeg in: SET_PRESSURE_ADVANCE ADVANCE=0.000

Herhaal voor elke 10 layers met oplopende waardes

CURA - SEARCH AND REPLACE
--------------------------
Search: ;LAYER:10  | Replace: ;LAYER:10\nSET_PRESSURE_ADVANCE ADVANCE=0.000
Search: ;LAYER:20  | Replace: ;LAYER:20\nSET_PRESSURE_ADVANCE ADVANCE=0.005
Search: ;LAYER:30  | Replace: ;LAYER:30\nSET_PRESSURE_ADVANCE ADVANCE=0.010
... etc

INSTELLEN NA TEST
-----------------
Console:
SET_PRESSURE_ADVANCE ADVANCE=0.032
SAVE_CONFIG

printer.cfg:
[extruder]
pressure_advance: 0.032

PER FILAMENT MACRO:
[gcode_macro SET_PA_PLA]
gcode: SET_PRESSURE_ADVANCE ADVANCE=0.032

═══════════════════════════════════════════════════════

EVALUATIE
---------
✓ Scherpe 90° hoeken
✓ Geen blobs bij richtingsveranderingen
✓ Consistente lijndikte
✓ Geen material buildup

✗ Te laag = ronde hoeken, blobs
✗ Te hoog = gaps, under-extrusie

TIPS
----
• Test bij normale print speed (60-80mm/s)
• Gebruik dezelfde temperatuur als je normaal print
• Herhaal test na grote wijzigingen (nieuwe nozzle, ander filament merk)

═══════════════════════════════════════════════════════
YouTube: Werkplaats Marc - Linear Advance Tutorial

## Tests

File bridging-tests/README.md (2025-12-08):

# Bridging Test Generator - Gebruikershandleiding

## 📋 Overzicht

Deze generator helpt je de optimale fan speed of bridge speed te vinden door **3 verschillende instellingen te testen in één print**. De test is verdeeld in 3 hoogtes, zodat je visueel direct kunt zien welke instelling het beste werkt.

## 🎯 Hoe het werkt

### De 3 Test Secties:
- **Sectie 1** (0-20mm hoogte): Onderste deel - Eerste test waarde
- **Sectie 2** (20-40mm hoogte): Middelste deel - Tweede test waarde  
- **Sectie 3** (40-60mm hoogte): Bovenste deel - Derde test waarde

### Waarom dit beter is dan layer-based:
✅ **Visueel duidelijk** - Je ziet direct welk deel beter print  
✅ **Geen verwarring** - Geen layers tellen, gewoon kijken naar onder/midden/boven  
✅ **Flexibel** - Test elke waarde combinatie die je wilt (50-75-100, of 70-80-90, etc.)

---

## 🚀 Stap-voor-Stap Instructies

### STAP 1: Download STL van GitHub

Kies een bridging test STL op basis van wat je wilt testen:

**GitHub locatie:** `github.com/werkplaatsmarc/3d-printer-kalibratie/bridging-tests/`

**Beschikbare STL files:**
- `bridging-test-10mm.stl` - Voor korte bridges (makkelijk)
- `bridging-test-20mm.stl` - Voor normale bridges (standaard)
- `bridging-test-30mm.stl` - Voor langere bridges (uitdagend)
- `bridging-test-40mm.stl` - Voor zeer lange bridges (moeilijk)
- `bridging-test-50mm.stl` - Voor extreme bridges (expert)

**💡 Tip:** Begin met 20mm als je niet zeker bent welke afstand relevant is voor jouw prints.

---

### STAP 2: Slice de STL in je Slicer

**In Cura / PrusaSlicer:**

1. Importeer de STL
2. Gebruik je **normale print instellingen**:
   - Layer hoogte: 0.2mm (aanbevolen)
   - Infill: 20%
   - Nozzle temp: Jouw normale PLA temp (bijv. 200°C)
   - Bed temp: Jouw normale bed temp (bijv. 60°C)
   - **Belangrijk**: Gebruik je HUIDIGE fan speed en bridge speed instellingen

3. Slice het model
4. **Exporteer de G-code**

**⚠️ Belangrijk:** Gebruik geen "Modifier Meshes" of "Height Range" instellingen. Laat de generator dit automatisch regelen!

---

### STAP 3: Open de Generator

Open `bridging-generator.html` in je webbrowser (Chrome, Firefox, Edge)

---

### STAP 4: Kies Test Type

**Optie A: Fan Speed Test** 💨
- Test verschillende cooling percentages
- Gebruik wanneer: Je bridging heeft last van drooping/sagging
-Voorbeeld waardes: 50%, 75%, 100%

**Optie B: Bridge Speed Test** 🚀
- Test verschillende print speeds voor bridges
- Gebruik wanneer: Je wilt sneller printen zonder kwaliteitsverlies
- Voorbeeld waardes: 20mm/s, 30mm/s, 40mm/s

**💡 Tip:** Begin ALTIJD met een Fan Speed Test. Bridge speed pas je pas aan als je optimale fan speed gevonden hebt.

---

### STAP 5: Configureer Test Waardes

#### Voor Fan Speed Test:

**Conservatieve test** (grote stappen):
- Sectie 1: 50%
- Sectie 2: 75%
- Sectie 3: 100%

**Fijnafstemming** (kleine stappen):
- Sectie 1: 70%
- Sectie 2: 80%
- Sectie 3: 90%

**Specifieke vergelijking:**
- Sectie 1: 60%
- Sectie 2: 100%
- Sectie 3: 100%
(Test of 60% al voldoende is)

#### Voor Bridge Speed Test:

**Conservatieve test:**
- Sectie 1: 15mm/s (langzaam, veilig)
- Sectie 2: 25mm/s (normaal)
- Sectie 3: 35mm/s (snel)

**Snelheidstest:**
- Sectie 1: 25mm/s
- Sectie 2: 40mm/s
- Sectie 3: 55mm/s

---

### STAP 6: Upload je G-Code

1. **Klik op het upload veld** of sleep je .gcode bestand ernaartoe
2. Wacht tot het bestand is geladen
3. Je ziet een groene bevestiging met de max Z-hoogte

**Verwachte max Z-hoogte:** Ongeveer 60-65mm (3 secties van elk ~20mm)

---

### STAP 7: Controleer Temperaturen

De generator haalt automatisch je slicer temperaturen over, maar je kunt ze nog aanpassen:

- **Nozzle temp:** Pas aan als je een andere temperatuur wilt testen
- **Bed temp:** Pas aan als je een andere bed temperatuur wilt testen

**💡 Tip:** Test maar één parameter tegelijk. Als je fan speed test, houd dan temperaturen constant!

---

### STAP 8: Genereer G-Code

1. Klik op **"Genereer Bridging Test G-Code"**
2. De aangepaste G-code wordt automatisch gedownload
3. Bestandsnaam: `bridging-fan-test-2024-12-08.gcode` (met datum)

---

### STAP 9: Preview de G-Code (BELANGRIJK!)

**Voor je gaat printen, controleer ALTIJD:**

#### In PrusaSlicer Preview:
1. Open PrusaSlicer
2. File → Import → Import G-code
3. Bekijk de preview
4. **Controleer:** Zie je 3 duidelijke secties?

#### In Tekstbestand (optioneel):
1. Open de .gcode in Kladblok
2. Zoek naar (Ctrl+F): `SECTIE 1`
3. Check of je de juiste waardes ziet:
```gcode
;==========================================
; SECTIE 1: 50%
; Z-hoogte 0-20mm
;==========================================
M106 S127 ; Set fan to 50%
```

4. Zoek naar `SECTIE 2` en `SECTIE 3` voor de andere waardes

---

### STAP 10: Print de Test

1. Kopieer de .gcode naar je SD kaart
2. Start de print
3. **Let op tijdens printen:**
   - Sectie 1 (onderste 20mm): Eerste instelling
   - Sectie 2 (middelste 20mm): Tweede instelling
   - Sectie 3 (bovenste 20mm): Derde instelling

**Print tijd:** Ongeveer 30-40 minuten (afhankelijk van bridge lengte)

---

### STAP 11: Evalueer het Resultaat

#### Bridging Kwaliteit Checklist:

**1. Onderkant (Bottom Surface)**
- ✅ **Perfect:** Glad, geen draden zichtbaar
- ⚠️ **Matig:** Lichte textuur, maar geen doorhang
- ❌ **Slecht:** Losse draden, doorhang, gaten

**2. Spanning**
- ✅ **Perfect:** Strak gespannen, geen doorhang in het midden
- ⚠️ **Matig:** Lichte doorhang (<1mm)
- ❌ **Slecht:** Duidelijke doorhang (>2mm)

**3. Bovenkant (Top Surface)**
- ✅ **Perfect:** Glad oppervlak, goed closed
- ⚠️ **Matig:** Kleine gaten maar geen openings
- ❌ **Slecht:** Grote gaten, slechte layer adhesie

#### Visuele Inspectie Tips:

**Met zaklamp:**
1. Houd een zaklamp onder de bridge
2. Kijk door de print heen
3. **Beste sectie:** Minste licht doorlaat = beste bridging

**Met schuifmaat (optioneel):**
1. Meet de doorhang in het midden van elke sectie
2. **Beste sectie:** Minste doorhang

---

### STAP 12: Pas Instellingen Toe

Zodra je de beste sectie hebt gevonden:

#### Voor Fan Speed Test:

**In Cura:**
1. Preferences → Printers → Machine Settings → Extruder
2. Zoek "Cooling" instellingen
3. Pas "Fan Speed" aan naar je winnende percentage

**In PrusaSlicer:**
1. Print Settings → Cooling
2. Pas "Max fan speed" aan naar je winnende percentage

#### Voor Bridge Speed Test:

**In Cura:**
1. Print Settings → Speed
2. Zoek "Bridge Speed"
3. Pas aan naar je winnende waarde

**In PrusaSlicer:**
1. Print Settings → Speed
2. Zoek "Bridges"
3. Pas aan naar je winnende waarde

---

## 🎓 Voorbeelden & Scenario's

### Scenario 1: Fan Speed te laag

**Symptomen:**
- Sectie 1 (50% fan): Grote doorhang, losse draden
- Sectie 2 (75% fan): Beter, maar nog steeds wat sag
- Sectie 3 (100% fan): Perfect!

**Conclusie:** Gebruik 100% fan voor bridging  
**Actie:** Pas fan speed aan in slicer naar 100%

---

### Scenario 2: Fan Speed optimaliseren

**Symptomen:**
- Sectie 1 (60% fan): Te veel doorhang
- Sectie 2 (80% fan): Perfect bridging!
- Sectie 3 (100% fan): Ook goed, maar geen verbetering

**Conclusie:** 80% fan is sweet spot  
**Actie:** Pas fan speed aan naar 80% (bespaart printtijd & lawaai)

---

### Scenario 3: Bridge Speed te snel

**Symptomen:**
- Sectie 1 (15mm/s): Perfect bridging
- Sectie 2 (25mm/s): Goed bridging
- Sectie 3 (35mm/s): Doorhang, slechte kwaliteit

**Conclusie:** 25mm/s is maximale veilige speed  
**Actie:** Gebruik max 25mm/s voor bridges

---

## ⚙️ Geavanceerde Tips

### Combinatie Testen

**Na je eerste fan test:**
1. Doe een fan speed test → Vind optimale fan speed (bijv. 85%)
2. Pas slicer aan naar 85% fan
3. Slice opnieuw met nieuwe fan setting
4. Doe een bridge speed test → Vind optimale speed
5. Pas beide instellingen toe in je profiel

### Materiaal-Specifieke Profielen

**PLA:**
- Fan: Meestal 75-100%
- Speed: 20-40mm/s

**PETG:**
- Fan: Meestal 30-60% (minder dan PLA!)
- Speed: 15-25mm/s (langzamer dan PLA!)

**ABS:**
- Fan: Meestal 0-30% (zeer weinig!)
- Speed: 20-30mm/s

**TPU:**
- Fan: 50-100%
- Speed: 10-20mm/s (zeer langzaam!)

### Multi-Material Testen

Als je met verschillende materialen werkt:
1. Maak een test voor elk materiaal
2. Label je SD kaart: "PLA-Bridging-Test.gcode", "PETG-Bridging-Test.gcode"
3. Bewaar resultaten in een notitie

---

## 🔧 Troubleshooting

### "Upload eerst een G-code bestand"
**Probleem:** Je probeert te genereren zonder G-code  
**Oplossing:** Upload eerst een geslicete .gcode file

### "Max Z-hoogte: 0mm"
**Probleem:** G-code bevat geen Z-bewegingen  
**Oplossing:** Check of je de juiste file hebt geüpload, slice opnieuw

### Download werkt niet
**Probleem:** Browser blokkeert download  
**Oplossing:** 
- Check browser download instellingen
- Probeer een andere browser (Chrome/Firefox)
- Rechtermuisknop → "Opslaan als..."

### Gcode ziet er raar uit in preview
**Probleem:** Speed test past te veel aan  
**Oplossing:** 
- Gebruik conservatievere speed waardes
- Check baseline speed in generator (standaard 25mm/s)

### Secties niet zichtbaar in print
**Probleem:** Z-detectie mislukt  
**Oplossing:** 
- Check of STL precies 60mm hoog is (3x 20mm)
- Slice met 0.2mm layers
- Check of slicer Z-hop niet interfereert

### Fan changes niet zichtbaar
**Probleem:** Originele M106 commando's overschrijven generator settings  
**Oplossing:** Generator verwijdert automatisch originele M106 commando's, maar check of er geen M107 (fan off) commando's in zitten

---

## 📊 Wat gebeurt er technisch?

### Fan Speed Test:

**Originele G-code:**
```gcode
M106 S255 ; Fan 100% (van slicer)
...
G1 Z5.0
...
```

**Aangepaste G-code:**
```gcode
;==========================================
; SECTIE 1: 50%
; Z-hoogte 0-20mm
;==========================================
M106 S127 ; Set fan to 50%

... printing moves tot Z=20 ...

;==========================================
; SECTIE 2: 75%
; Z-hoogte 20-40mm
;==========================================
M106 S191 ; Set fan to 75%

... printing moves tot Z=40 ...

;==========================================
; SECTIE 3: 100%
; Z-hoogte 40-60mm
;==========================================
M106 S255 ; Set fan to 100%

... printing moves tot Z=60 ...
```

### Bridge Speed Test:

**Originele move:**
```gcode
G1 F1500 X100 Y100 E5.0
```

**Aangepaste move (30mm/s target, baseline 25mm/s):**
```gcode
G1 F1800 X100 Y100 E5.0
```
(1500 * (30/25) = 1800)

---

## 🎯 Veelgestelde Vragen (FAQ)

**Q: Kan ik meer dan 3 secties testen?**  
A: Nee, de generator is ontworpen voor 3 secties. Voor meer granulariteit doe je meerdere tests met verschillende ranges.

**Q: Moet ik altijd bij 0-20-40mm splitsen?**  
A: Ja, dit is hard-coded voor consistentie. Je STL moet dus 60mm hoog zijn.

**Q: Kan ik zowel fan speed als bridge speed tegelijk testen?**  
A: Nee, test één parameter tegelijk voor duidelijke resultaten.

**Q: Werkt dit met elke slicer?**  
A: Ja, zolang de slicer G-code output met Z-coördinaten produceert (alle moderne slicers).

**Q: Moet ik de STL van GitHub gebruiken?**  
A: Niet per se, maar de generator verwacht wel 3 secties van elk 20mm (totaal 60mm).

**Q: Kan ik de secties groter/kleiner maken?**  
A: Niet zonder de generator code aan te passen. 20mm per sectie is optimaal voor duidelijke resultaten.

---

## 📝 Workflow Samenvatting

```
1. Download STL (10/20/30/40/50mm) van GitHub
   ↓
2. Slice in Cura/PrusaSlicer (normale settings)
   ↓
3. Open bridging-generator.html
   ↓
4. Kies: Fan Speed Test OF Bridge Speed Test
   ↓
5. Vul 3 test waardes in
   ↓
6. Upload geslicete G-code
   ↓
7. Genereer aangepaste G-code
   ↓
8. Preview in slicer (optioneel maar aanbevolen)
   ↓
9. Print test (~30-40 min)
   ↓
10. Evalueer: Welke sectie is beste?
   ↓
11. Pas winnende waarde toe in slicer profiel
   ↓
12. Klaar! 🎉
```

---

## 📞 Support

**Website:** werkplaatsmarc.be  
**YouTube:** @werkplaatsmarc  
**GitHub:** github.com/werkplaatsmarc/3d-printer-kalibratie

Heb je vragen of suggesties? Laat een comment achter op YouTube of open een issue op GitHub!

---

**Versie:** 2.0 (Z-hoogte based)  
**Laatst bijgewerkt:** December 2024  
**Auteur:** Marc - Werkplaats Marc

Veel success met je bridging kalibratie! 🌉

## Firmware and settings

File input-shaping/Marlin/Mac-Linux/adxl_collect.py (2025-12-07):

"""
ADXL345 Data Verzameling Script
Werkplaats Marc - Input Shaping Kalibratie
GitHub: https://github.com/werkplaatsmarc/3d-printer-kalibratie

Dit script verzamelt accelerometer data van de BigTreeTech ADXL345 v2.0
voor Input Shaping kalibratie op Ender 3 V2 met Marlin firmware.

Aangepast voor gebruik met batch launcher.
"""

import serial
import time
import csv
from datetime import datetime
import os
import sys

class ADXL345:
    """ADXL345 accelerometer interface klasse"""
    
    # ADXL345 Register adressen
    POWER_CTL = 0x2D
    DATA_FORMAT = 0x31
    BW_RATE = 0x2C
    DATAX0 = 0x32
    
    # Instellingen
    MEASURE_MODE = 0x08
    FULL_RESOLUTION = 0x08
    RANGE_16G = 0x03
    RATE_3200HZ = 0x0F
    
    def __init__(self, serial_port):
        self.serial = serial_port
        self.scale = 0.004  # 4mg per LSB in full resolution mode
        
    def initialize(self):
        """Initialiseer ADXL345 voor hoge snelheid data acquisitie"""
        print("⚙️  ADXL345 initialiseren...")
        
        # Standby mode
        self.write_register(self.POWER_CTL, 0x00)
        time.sleep(0.1)
        
        # Data format: Full resolution, ±16g
        self.write_register(self.DATA_FORMAT, self.FULL_RESOLUTION | self.RANGE_16G)
        
        # Bandwidth rate: 3200 Hz
        self.write_register(self.BW_RATE, self.RATE_3200HZ)
        
        # Measurement mode
        self.write_register(self.POWER_CTL, self.MEASURE_MODE)
        time.sleep(0.1)
        
        print("✅ ADXL345 gereed voor data acquisitie")
        
    def write_register(self, register, value):
        """Schrijf naar ADXL345 register via I2C"""
        cmd = f"W{register:02X}{value:02X}\n"
        self.serial.write(cmd.encode())
        time.sleep(0.01)
        
    def read_acceleration(self):
        """Lees X, Y, Z acceleratie data"""
        # Request data
        cmd = f"R{self.DATAX0:02X}06\n"
        self.serial.write(cmd.encode())
        
        # Lees response
        try:
            response = self.serial.readline().decode().strip()
        except UnicodeDecodeError:
            return None, None, None
        
        if len(response) >= 12:
            try:
                # Parse hex data naar raw waarden
                x_raw = int(response[0:4], 16)
                y_raw = int(response[4:8], 16)
                z_raw = int(response[8:12], 16)
                
                # Converteer naar signed integers
                if x_raw > 32767:
                    x_raw -= 65536
                if y_raw > 32767:
                    y_raw -= 65536
                if z_raw > 32767:
                    z_raw -= 65536
                
                # Schaal naar g waarden
                x = x_raw * self.scale
                y = y_raw * self.scale
                z = z_raw * self.scale
                
                return x, y, z
            except (ValueError, IndexError):
                return None, None, None
        
        return None, None, None

def collect_data(com_port, duration, sample_rate, output_file):
    """Verzamel accelerometer data voor resonantie analyse"""
    
    print("\n" + "="*70)
    print("🔧 WERKPLAATS MARC - ADXL345 DATA VERZAMELING")
    print("="*70 + "\n")
    
    # Verbind met ADXL345
    print(f"🔌 Verbinden met {com_port}...")
    
    try:
        ser = serial.Serial(com_port, 115200, timeout=1)
        time.sleep(2)  # Wacht op connectie
        print(f"✅ Verbonden met {com_port}\n")
    except serial.SerialException as e:
        print(f"❌ FOUT: Kan niet verbinden met {com_port}")
        print(f"   {e}")
        print("\n💡 TIP: Check COM poort in Windows Apparaatbeheer")
        sys.exit(1)
    
    # Initialiseer ADXL345
    adxl = ADXL345(ser)
    try:
        adxl.initialize()
    except Exception as e:
        print(f"❌ FOUT bij initialiseren: {e}")
        ser.close()
        sys.exit(1)
    
    print("\n" + "="*70)
    print("📊 START DATA VERZAMELING")
    print("="*70)
    print(f"\n⏱️  Duur: {duration} seconden")
    print(f"📈 Sample rate: {sample_rate} Hz")
    print(f"💾 Output: {output_file}")
    print("\n🎯 RAAK DE PRINTER NIET AAN!")
    print("   Data verzameling start in 3 seconden...\n")
    
    for i in range(3, 0, -1):
        print(f"   {i}...")
        time.sleep(1)
    
    print("\n🚀 DATA VERZAMELING ACTIEF!\n")
    
    # Open CSV bestand
    try:
        with open(output_file, 'w', newline='') as csvfile:
            writer = csv.writer(csvfile)
            writer.writerow(['Timestamp', 'X_accel', 'Y_accel', 'Z_accel'])
            
            start_time = time.time()
            sample_count = 0
            last_progress_time = start_time
            
            # Verzamel data
            while (time.time() - start_time) < duration:
                timestamp = time.time() - start_time
                x, y, z = adxl.read_acceleration()
                
                if x is not None:
                    writer.writerow([f"{timestamp:.6f}", f"{x:.6f}", f"{y:.6f}", f"{z:.6f}"])
                    sample_count += 1
                    
                    # Progress indicator elke seconde
                    if (time.time() - last_progress_time) >= 1.0:
                        elapsed = int(timestamp)
                        remaining = duration - elapsed
                        progress = (elapsed / duration) * 100
                        
                        # Progress bar
                        bar_length = 40
                        filled_length = int(bar_length * elapsed / duration)
                        bar = '█' * filled_length + '░' * (bar_length - filled_length)
                        
                        print(f"\r⏳ [{bar}] {progress:.0f}% | {elapsed}s / {duration}s | {sample_count} samples", end='', flush=True)
                        last_progress_time = time.time()
                
                # Controleer sample rate
                time.sleep(max(0, 1.0 / sample_rate))
        
        print("\n\n" + "="*70)
        print("✅ DATA VERZAMELING VOLTOOID!")
        print("="*70)
        print(f"\n📊 Totaal verzamelde samples: {sample_count}")
        print(f"💾 Data opgeslagen in: {output_file}")
        print("="*70 + "\n")
        
    except Exception as e:
        print(f"\n❌ FOUT bij schrijven naar bestand: {e}")
        ser.close()
        sys.exit(1)
    
    ser.close()

if __name__ == "__main__":
    # Parse command line argumenten
    if len(sys.argv) < 5:
        print("❌ FOUT: Onvoldoende argumenten")
        print("Gebruik: python adxl_collect.py <COM_PORT> <DURATION> <SAMPLE_RATE> <OUTPUT_FILE>")
        sys.exit(1)
    
    try:
        com_port = sys.argv[1]
        duration = int(sys.argv[2])
        sample_rate = int(sys.argv[3])
        output_file = sys.argv[4]
        
        collect_data(com_port, duration, sample_rate, output_file)
        
    except KeyboardInterrupt:
        print("\n\n⚠️  Data verzameling gestopt door gebruiker")
        sys.exit(1)
    except Exception as e:
        print(f"\n❌ FOUT: {e}")
        import traceback
        traceback.print_exc()

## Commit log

2025-10-05 Upload Downloadbare bestanden
    [bridging-test-universeel.stl, linear-advance-test-pattern.stl, retractie-toren-bowden - afstand 4-9.3mf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]
2025-10-05 Bestandnamen aangepast
    [retractie-toren-bowden-afstand-4-9.3mf, retractie-toren-direct-drive-afstand-1-6.3mf, retractie-toren-tpu-flexibel-afstand-7-12.3mf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]
2025-10-06 input shaping toevoegen
    [ringing_tower.stl]
2025-10-06 toevoegen stl
2025-12-04 Nieuwe structuur: Marlin en Klipper gescheiden
    - Marlin tools voor Windows en Mac/Linux
    - Aparte Klipper documentatie (alleen docs, geen tools)
    - README structuur met firmware keuze
    - .gitignore toegevoegd
2025-12-08 overhand test toevoegen
    [verhang-angle-test.stl]
2025-12-08 bridging stl's toegevoegd
    [bridging-test-10mm.stl, bridging-test-20mm.stl, bridging-test-30mm.stl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]
2025-12-14 update stl bestanden
    [bridging-test-10mm.stl, bridging-test-20mm.stl, bridging-test-30mm.stl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]
2025-12-14 Toevoegen stl's voor genrator
    [retraction-tower-bowden.stl, retraction-tower-direct.stl, retraction-tower-tpu.stl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]
2026-01-19 waardes op torens aanwezig
    [retraction-tower-direct.stl, retraction-tower-tpu.stl]
2026-01-19 blank toren toegevoegd
    [retraction-tower-blank.stl]

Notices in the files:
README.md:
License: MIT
